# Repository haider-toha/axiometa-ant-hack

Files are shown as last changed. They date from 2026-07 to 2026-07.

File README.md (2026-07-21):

# Tacta

Tacta is an open project toward one wearable device. The device gives DeafBlind
people a sense of the world around them, through touch. It fuses several senses
into vibration.

Cameras read the scene. Microphones pick out important sounds. Depth sensors
feel the space around the wearer. Tacta turns all three into touch. The project
is open source so more people, more money, and better engineering can build the
real thing.

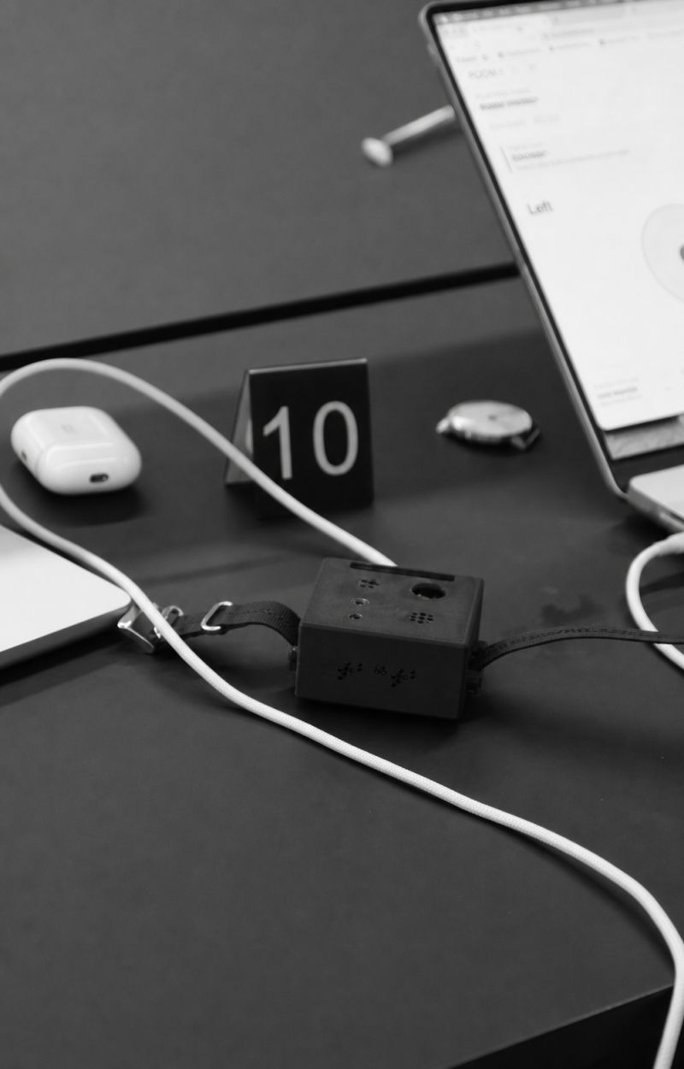
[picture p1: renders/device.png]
The Tacta prototype device


This repository holds a hackathon prototype. The team built it at the Axiometa
and Anthropic hardware hack in London, from 17 to 19 July 2026. The prototype
wires the idea end to end with off-the-shelf modules and a phone camera. It
locks the demo to one concrete scene so the story stays clear. The scene reads a
specific bus at a stop. That scene is one example, not the product.

> Honest scope. This is a hackathon prototype, not a finished accessibility
> product. The two on-board buzzers failed the bench haptic test. They now stand
> in as two audible tones for two future vibration channels. The single depth
> sensor gives a clearance warning, not navigation. The team has not tested Tacta
> with DeafBlind people. Read the [Limitations](#limitations) section.

## How it senses the world

Tacta fuses three channels. Each channel does a small job today. Each channel
points at a larger job in the real product.

### Vision

The cameras read the scene. Today, the phone camera sends frames to a cloud
vision service. The service finds objects and reads text, like a route number on
a vehicle or the words on a sign. A future version uses on-board cameras. It
reads more of the scene, including what is ahead and what is approaching.

### Sound

The microphones pick out important sounds. Today, one on-board microphone detects
a siren on the device, offline. A future version classifies more sounds. It can
flag a car horn, a barking dog, an alarm, or someone calling out.

### Depth

The depth sensors feel the space around the wearer. Today, one forward sensor
gives a clearance warning, not navigation. A future version senses a fuller field
around the body. It moves closer to a dome than a single line.

## System diagram

```mermaid
flowchart LR
  cam["Phone camera, capture page"] -->|"JPEG frames, 2 Hz"| modal["Modal vision service, YOLO and Claude"]
  modal -->|"reading and bearings"| relay["Vercel and Upstash relay"]
  relay -->|"outbound poll"| board["ESP32-S3 board"]
  mic["PDM microphone"] -->|"siren, local"| board
  depth["Depth sensor"] -->|"clearance, local"| board
  board --> out["Vibration output, two audible stand-ins today"]
```

## Hardware

An ESP32-S3 "Genesis Mini" board carries four snap-in modules. A phone browser
camera supplies the video. All four ports are occupied today.

| Port | Module | Function |
|---|---|---|
| `P1` | AX22-0018 passive buzzer | An audible tone at 2350 Hz. A stand-in for a future vibration channel |
| `P2` | VL53L0CX time-of-flight sensor | A forward clearance warning. Not navigation |
| `P3` | AX22-0018 passive buzzer | An audible tone at 3050 Hz. A stand-in for a future vibration channel |
| `P4` | AX22-0044 PDM microphone | Local siren detection |
| Phone camera | Phone browser camera | Live scene video through the capture page |

The end product puts the cameras, microphones, and depth sensors on one custom
board.

## Software stack

Four parts meet at the shared contract in
[`app/src/lib/contract.ts`](app/src/lib/contract.ts).

- **`app/`** is a Next.js 16 web app on Vercel and Upstash Redis. It serves the
  pitch deck at `/`. It runs the phone camera capture, the device relay, and the
  output and relay monitors. See [`app/README.md`](app/README.md).
- **`vision/service.py`** is a Modal service. It runs YOLO detection. Then Claude
  reads the route text under a strict JSON schema. The demo locks the reading to
  route 88 and Clapham Common. See [`MODAL-FOR-APP.md`](MODAL-FOR-APP.md).
- **The relay** runs on Vercel and Upstash Redis. It carries commands to the
  board. The board polls the relay outbound only. The board never accepts an
  inbound connection. See [`RELAY-FOR-FIRMWARE.md`](RELAY-FOR-FIRMWARE.md).
- **`firmware/braille_wearable/`** holds the PlatformIO firmware, environment
  `board_firmware`. It runs the local siren and depth paths offline. The
  directory keeps its old name so the firmware build does not break.

### Demo phases

The demo runs in two activity phases. The phone reports the phase.

- In `MOVING`, the board keeps the local depth and siren alerts active. It holds
  the arrival output silent. The cane stays the primary mobility aid.
- In `STILL`, the board stops the depth output. It keeps the siren active. It
  shows the arrival reading and the route-88 output.

Camera bearings (`LEFT`, `RIGHT`, `AHEAD`) are advisory. They tell the wearer
where the target sits in frame. They work in both phases. They never outrank the
local depth and siren paths.

## Quick start

Each area has its own doc with the full sequence. Do not copy flags from memory.

Start the web app from `app/`.

```bash
cd app
pnpm install
pnpm run build
```

See [`app/README.md`](app/README.md) for the dev server and the env setup.

Build the firmware from `firmware/braille_wearable/`.

```bash
cd firmware/braille_wearable
pio run -e board_firmware
```

For the rest, read the area docs. [`MODAL-FOR-APP.md`](MODAL-FOR-APP.md) deploys
the Modal vision service. [`RELAY-FOR-FIRMWARE.md`](RELAY-FOR-FIRMWARE.md) covers
the relay and the firmware contract. [`DEMO-RUNBOOK.md`](DEMO-RUNBOOK.md) runs the
demo with the stage sequence and the fallbacks.

## Repository map

| Path | Contents |
|---|---|
| [`app/`](app/) | Next.js 16 web app. Pitch deck, capture page, device relay, monitors |
| [`vision/`](vision/) | Modal vision service (`service.py`). YOLO detection and Claude route reading |
| [`firmware/`](firmware/) | PlatformIO ESP32-S3 firmware, environment `board_firmware` |
| [`cad/`](cad/) | Parametric enclosure (`enclosure.py`) with exported `enclosure.step` and `enclosure.stl` |
| [`demo/`](demo/) | Demo fixtures, including the synthetic siren audio |
| [`renders/`](renders/) | Device renders |
| [`docs/`](docs/) | Forward-direction notes, including the vibration-motor upgrade path |
| [`plan/`](plan/) | The authoritative plan |

## Limitations

This is a hackathon prototype. These limits are load-bearing, not disclaimers.

- Tactile output failed. The two AX22-0018 buzzers are audible stand-ins at
  2350 Hz and 3050 Hz. They are not working haptics. They prove nothing about
  body-worn vibration.
- The depth sensor is not navigation. The single forward zone gives a clearance
  warning only. No local sensor output is navigation.
- The team has not tested with DeafBlind people. This is a prototype, not an
  accessibility product. Nothing about us without us.
- Route 88 and Clapham Common are hardcoded on purpose. This is a demo lock, not
  general scene reading.

## Where this could go

The real product is purpose-built. This is the invitation to build it.

- One integrated device. A custom PCB carries the cameras, the microphones, and
  the depth sensors on one board.
- Real haptics. A proper array of vibration actuators replaces the two buzzers.
  See [`docs/lra-motor-upgrade.md`](docs/lra-motor-upgrade.md) for the near-term
  motor swap.
- A form factor that fits the wearer. It need not be a wrist unit. It can be a
  chest harness, a necklace, or something else.
- Richer sound. The microphones classify many sounds, not one siren.
- A fuller depth field. The sensors feel a field around the body, closer to a
  dome than a single line.

If you can build this properly, take it and run.

## Contributing

[`AGENTS.md`](AGENTS.md) documents the AI-assisted workflow. Claude Code and Codex
both work from that file. Read it before you change code. CI runs on every pull
request through [`.github/workflows/verify.yml`](.github/workflows/verify.yml).
Run the verification commands for the area you touch.

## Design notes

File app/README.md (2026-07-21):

# Tacta web app

This is the Next.js 16 web app for the Tacta prototype. It does four jobs.

1. It serves the pitch deck as the public landing page.
2. It captures phone camera frames and posts them to the Modal vision service.
3. It runs the outbound-only device relay that the ESP32 polls, backed by Upstash Redis.
4. It runs two debug monitors, one for the device output and one for the relay state.

The shared wire contract lives in [`src/lib/contract.ts`](src/lib/contract.ts).
It is the source of truth for the command, activity, and telemetry types. See
[`../MODAL-FOR-APP.md`](../MODAL-FOR-APP.md) for the Modal contract.

The stack is Next.js 16.2 (App Router), React 19, Tailwind v4 with shadcn on
Base UI, Upstash Redis, the Anthropic SDK, and Vitest.

## Pages

The landing route `/` serves the pitch deck. A rewrite in
[`next.config.ts`](next.config.ts) maps `/` to `public/deck/index.html`, so the
URL stays `/`. The deck is a static scrollytelling site. Its final call to
action links to `/capture`.

| Route | File | Function |
|---|---|---|
| `/` | `public/deck/index.html` (rewrite) | The pitch deck. A static scrollytelling site served at the site root |
| `/capture` | `src/app/capture/page.tsx` | The capture page. It opens the rear camera with `getUserMedia`. It grabs a `<canvas>` JPEG at 2 Hz (`CAPTURE_MS = 500`). It POSTs the base64 frame to the Modal detector (`NEXT_PUBLIC_MODAL_URL`, or `?modal=<url>`). It maps the detector response to a relay command and posts it on change. It also owns the `STILL` and `MOVING` activity control and the person-direction path |
| `/output` | `src/app/output/page.tsx` | The output monitor. It reads `TACTA_OUTPUT` telemetry from the ESP32 over Web Serial. It shows the P1 and P3 output channels and the pulse history. Desktop Chrome only |

## API routes

The API routes live under [`src/app/api/`](src/app/api/). All relay state lives
in Upstash Redis. The app writes the payload with `mset` before it increments
`seq`. This ordering is the race fix. Preserve it.

| Route | Method | Purpose |
|---|---|---|
| `/api/pull` | GET, POST | The ESP32's outbound poll. A POST body carries device telemetry, stored for the monitor. The response is the current `DeviceCommand`. A GET returns the command and writes no telemetry, which is handy for a `curl` smoke test |
| `/api/event` | POST | It ingests a camera-derived command and writes relay state. The command set lives in [`src/lib/contract.ts`](src/lib/contract.ts). It covers the arrival, wait, route-number, and unknown patterns, plus the advisory `LEFT`, `RIGHT`, and `AHEAD` bearings |
| `/api/activity` | POST | The `STILL` and `MOVING` activity channel and its heartbeat. It advances `activitySeq` and `activityTs` independently of the command `seq` and `ts` |
| `/api/person-direction` | POST | Person and obstacle handling in `MOVING`. It takes a normalized box and asks Claude which side has clear pavement. It fails closed. It uses `ANTHROPIC_API_KEY` at request time |
| `/api/detector` | POST | It records the raw Modal detector state for the debug screen |
| `/api/state` | GET | An aggregate debug snapshot of command, detector, and telemetry |

## Local development

```bash
pnpm install
cp .env.example .env.local
pnpm dev
```

The dev server runs at http://localhost:3000. Set the values from
[`.env.example`](.env.example).

| Variable | Needed for |
|---|---|
| `UPSTASH_REDIS_REST_URL`, `UPSTASH_REDIS_REST_TOKEN` | Relay state. `Redis.fromEnv()` requires both |
| `NEXT_PUBLIC_MODAL_URL` | The Modal detector endpoint the capture page POSTs to. Public, or pass `?modal=<url>` on `/capture` |
| `ANTHROPIC_API_KEY` | The request-time Claude call in `/api/person-direction` |

The production relay is https://tacta.space. Never commit `.env.local`. The repo
tracks only the empty `.env.example` template.

## Verification

```bash
pnpm exec tsc --noEmit
pnpm run lint
pnpm run build
pnpm test
```

`pnpm run build` can print Upstash missing-env warnings in a local shell. It must
still finish. Run the pre-demo readiness gate before the demo.

```bash
pnpm demo:readiness -- --base-url https://tacta.space
```

See [`../DEMO-RUNBOOK.md`](../DEMO-RUNBOOK.md) for the full readiness gate and the
fallbacks.

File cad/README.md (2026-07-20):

# Tacta wearable enclosure CAD

Tacta is a wearable that gives situational awareness through touch. This is the
parametric enclosure for the wrist-worn device. It wraps the Axiometa "Genesis
Mini" host board (55 x 55 mm) and its four snap-in AX22 modules.

| Port | Module | Aperture in the shell |
|---|---|---|
| P1 / P3 | passive buzzers | two buzzer grilles |
| P2 | VL53L0CX ToF | one ToF "eye" |
| P4 | microphone | mic port(s), this module governs the deck height |

The shell is a **closed monolith**. A solid deck carries only functional
openings. These are the ToF eye, the mic ports, the trimpot access, the buzzer
grilles, and a button-access slot. The one decorative feature is the raised
"TACTA" branding on the −X wall. It pierces nothing and is **not** an
accessibility feature.

## `enclosure.py`

`enclosure.py` is a **Fusion 360 Python script**. It authors every
dimension in millimetres. It converts to Fusion's internal centimetres through a
single `_cm()` chokepoint. It produces two bodies. `cage` holds the shell, lugs,
strap bars, and branding. `skin_plate` holds the base plate, corner gussets, and
M2 standoffs. So the base carries the board, and the cage drops over it.

**In Fusion.** Open a Design document. Then open *Utilities*, *Add-Ins*,
*Scripts and Add-Ins*. Add this file and run it. The Fusion entry point is
`run(context)`.

**Headless, no Fusion.** The script falls back to
[`tests/fake_adsk/`](tests/fake_adsk). This is a real
[build123d](https://github.com/gumyr/build123d) geometry engine behind a fake
`adsk` API. So it builds and **exports STEP and STL** without the Fusion GUI.

```bash
python cad/enclosure.py
```

This writes `enclosure.step` and `enclosure.stl` as fit-check
artifacts. The headless harness records chamfers but does not apply them. So the
exported solids are sharp-edged relative to the in-Fusion build.

## `reference/`

[`reference/genesis-mini-shell.step`](reference/genesis-mini-shell.step) is a
**known-good, physically printed** Genesis Mini shell from Printables. It serves
as the fit reference. This shell already seats the board and modules. Check
openings, clearances, and envelope against it before you trust our own model
alone. See [`reference/README.md`](reference/README.md) for provenance and its
different original module layout.

## `tests/`

Fusion has no headless mode. So geometry-logic bugs otherwise surface only inside
the GUI. These bugs include boolean-miss cuts, sketch-plane orientation
assumptions, and dimension regressions. The suite runs the enclosure script
**offline** against `fake_adsk` and probes the result. It catches that whole
class of bug without Fusion.

```bash
.venv/bin/python -m pytest cad/tests -q
```

The venv needs `pytest` and `build123d`. If it is absent, the geometry suite
cannot run. The in-Fusion build remains ground truth. This suite is a fast
regression net, not a substitute. See [`tests/README.md`](tests/README.md) for
what the harness can and cannot catch.

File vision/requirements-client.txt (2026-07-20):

# Dependencies for `python vision/client.py`, the local test client.
#
# Separate from requirements.txt on purpose: that file is scoped to the machine
# that runs `modal deploy` and lists only what service.py imports at module
# level. A camera/GUI dependency does not belong there.
#
#   pip install -r vision/requirements-client.txt
#
# The browser capture path (app/src/app/capture/page.tsx) needs nothing installed here.

# The only non-stdlib import in client.py. HTTP goes through urllib.request,
# so there is no `requests` dependency to pin.
opencv-python

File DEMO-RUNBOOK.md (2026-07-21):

# Tacta Demo Runbook

Tacta is an open project toward one wearable that gives DeafBlind people
situational awareness through touch. It fuses cameras, microphones, and depth
sensors and delivers the result as vibration. This runbook drives the hackathon
demo. The demo hardcodes one concrete scene, reading a specific bus at a stop,
route `88` / `Clapham Common`. That scene is one hardcoded example of the
product, not the product itself.

The cane remains the primary mobility aid. The single forward ToF sensor detects
clearance only. It cannot choose a safe left or right bypass. The buzzers are
audible stand-ins for two future vibration channels. The first-hour tactile test
failed, so treat them as proxies only. Nothing here is validated with DeafBlind
users.

The live site tacta.space serves the pitch deck as the landing page. The demo
tools live at `/capture` and `/output`.

## Readiness Gate

Run the readiness command from `app/`.

```bash
pnpm demo:readiness -- --base-url https://tacta.space
```

Do not start the audience demo until it prints `READY`. Haider owns the phone
motion classifier and the relay activity heartbeat. This repo consumes that
state. It does not replace the producer.

The morning demo firmware boots in `AUDIBLE` mode. This stops a reset or power
cycle from disabling P1 and P3 without warning. Send service Serial `q` for a
deliberate quiet rehearsal. Sensors, relay handling, and `TACTA_OUTPUT`
telemetry continue while the buzzer GPIO drives stay muted.

## Hardware And Topology

| Port | Module | Firmware signal |
|---|---|---|
| P1 | AX22-0018 passive buzzer | GPIO3, left/channel A |
| P2 | VL53L0CX ToF | SDA GPIO10, SCL GPIO11, XSHUT GPIO6 |
| P3 | AX22-0018 passive buzzer | GPIO16, right/channel B |
| P4 | AX22-0044 PDM microphone | CLK GPIO18, data GPIO17, select GPIO1 high, I2S0 |

The phone runs Chrome or Safari at the deployed `/capture` route on a 2.4 GHz
hotspot. The ESP32 joins the phone hotspot and polls Vercel outbound only. The
MacBook powers the ESP32 over USB-C. The MacBook opens the deployed `/output`
route in desktop Chrome for Web Serial.

PlatformIO Serial Monitor and `/output` cannot own the USB serial port at the
same time. Close one before you open the other.

## Morning Setup

1. Pull `main` and confirm it includes the audible-default demo firmware.
2. Create the ignored file `firmware/braille_wearable/src/secrets.h` from
   `secrets.example.h`. Add only the phone hotspot SSID and password. The file
   `network_config.h` tracks the deployed relay host.
3. Enable the phone hotspot. On iPhone, enable **Maximize Compatibility**. On
   Android, choose the 2.4 GHz band.
4. Build and upload `board_firmware`.

   ```bash
   cd firmware/braille_wearable
   $HOME/.platformio/penv/bin/pio run -e board_firmware
   $HOME/.platformio/penv/bin/pio run -e board_firmware -t upload --upload-port /dev/cu.usbmodem1101
   ```

5. Confirm the board boots in `AUDIBLE` mode. Send `q` only for a quiet
   rehearsal. Send `v` before the audience demo.
6. Open `/capture` on the phone, grant camera access, and frame the A4 route prop.
7. Open `/output` in desktop Chrome. Select the ESP32. Confirm live idle
   telemetry. The display shows the requested logical frequencies in either
   output mode.
8. Run the readiness command until every route, contract, and activity
   freshness check passes.
9. Wait for the board to record its first activity baseline. Then make Haider's
   producer send a fresh `MOVING` transition. A baseline alone does not grant
   cloud control.

## Exact Demo Sequence

1. **Moving.** Confirm `/api/pull` reports fresh `MOVING`. Bring a blockade into
   the forward ToF zone. Expect P1 proximity pulses on `/output`. Choose the
   bypass with the cane and verify it. Then clear the blockade.
2. **Ambulance.** In daytime only, play the validated siren sample at the
   rehearsed level. Expect the local siren output to preempt proximity and
   signal a stop. Do not claim general environmental-sound recognition.
3. **Still.** Haider's producer changes activity to fresh `STILL`. Confirm the
   readiness probe still passes. Confirm the board suppresses ToF output.
4. **Direction (audit 23).** While `STILL`, hold the route prop to one side of
   the camera frame. Wait for the three-frame confirmation. Then expect `LEFT`,
   `RIGHT`, or `AHEAD` on `/output`. Bearings deliver in **both** activity
   phases. The user scans for the target while standing still. While an arrival
   or route reading is active, that information takes the shared channel first.
   The capture page then shows the direction as `held (…)`. The "Force send"
   toggle on `/capture` makes the direction outrank it.
5. **Arrival.** Move the printed route-88 prop steadily through the phone camera.
   Expect `BUS`, then `WAIT`, then a high-confidence `NUMBER` with route `88`.
6. **Output.** Confirm `/output` shows both logical channels and the pulse
   history. In audible mode, the buzzers mirror those signals. In night mode,
   the buzzers stay muted.
7. **Reset.** Remove the prop. Return activity to fresh `MOVING` before the next
   run.

## Output Controls

Use service Serial only while `/output` is disconnected.

| Key | Result |
|---|---|
| `q` | Night mode. Hardware muted, logical patterns and telemetry continue |
| `v` | Audible mode. Energize the buzzers for a daytime rehearsal |
| `x` | Emergency stop. Clear all output, sensing continues |
| `o` | Resume output processing after `x` |
| `n` / `s` | Diagnostic MOVING/STILL override |
| `c` | Clear diagnostic override and return control to Haider's relay state |
| `b` / `w` / `8` | Diagnostic BUS/WAIT/NUMBER-88 inputs |

The Serial connection can reset the board when you open it. The morning demo
build returns to audible output after that reset. Send a control, then close
Serial Monitor before you reconnect `/output`.

## Fallbacks And Stop

- For stale or missing activity, use `n` or `s` only as a disclosed diagnostic
  fallback. Do not present it as phone motion classification.
- For a vision or Modal failure, use `b`, `w`, and `8` only as a disclosed
  board-only fallback. Do not claim the board read the printed route.
- For a deployed `/output` failure, run `pnpm dev -- -p 3012` from `app/`. Then
  open `http://localhost:3012/output` in Chrome.
- For an unreadable or low-confidence route, expect `UNKNOWN`. Never substitute
  `88`.
- For an unexpected sound, send `q`. If output continues, send `x`. Then
  disconnect USB-C power.
- For a full stop, stop camera capture, return relay activity to `MOVING`, send
  `q`, disconnect `/output`, and unplug the board.

## Five-Minute Rehearsal

- The readiness command prints `READY`.
- The board holds hotspot credentials and starts in audible mode.
- `/capture` sees the complete A4 prop in stable light.
- `/output` receives fresh telemetry in desktop Chrome.
- Fresh `MOVING` produces the ToF visualization. Fresh `STILL` suppresses it.
- `BUS`, `WAIT`, and `NUMBER` 88 arrive in order while `STILL`.
- `q` and `x` stop hardware output as expected before you admit an audience.

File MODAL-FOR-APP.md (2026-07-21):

# Web app to Modal vision contract

This is the handoff spec for the Modal vision service (`vision/service.py`). It defines the one HTTP contract that the web app (`app/`) speaks to Modal. Get this shape right, and the front end needs no changes.

Tacta gives situational awareness through touch. It fuses cameras, microphones, and depth sensors and delivers the result as vibration. This endpoint is the vision sense. The demo hardcodes one concrete scene, reading a specific bus at a stop, route `88` to `Clapham Common`. That scene is one hardcoded example, not the product. The web app that calls this endpoint ships on the live site tacta.space, which serves the pitch deck as its landing page and the demo tools at `/capture` and `/output`.

The source of truth for the types is [`app/src/lib/contract.ts`](app/src/lib/contract.ts). It exports `ModalResponse`, `ModalReading`, and `detectorToEvent`. For full background, read [`plan/2026-07-18-situational-awareness.md`](plan/2026-07-18-situational-awareness.md). See the sections "Data Contracts, Contract A" and "The Vision Pipeline".

---

## Summary

- Expose **one public HTTPS POST endpoint** on Modal as a web endpoint. Callers need **no auth**. The browser posts directly to it.
- The web app sends a JPEG frame about **2 times per second**. The endpoint replies with the current **arrival state**, not a bounding box.
- The endpoint must send **CORS headers and answer the `OPTIONS` preflight**. The call is cross-origin from the browser. This is the single most common thing that breaks it.
- The web app needs only the **deployed URL** back from you. It goes into the app as `NEXT_PUBLIC_MODAL_URL`, or as `?modal=<url>` on the capture page. The Modal **token** is for deployment, not for the app. Never put it in `app`.

---

## The endpoint

`POST https://<workspace>--tacta-vision-ingest.modal.run` (name is up to you)

### Request body (what the phone sends)

```jsonc
{
  "frame_b64": "/9j/4AAQSkZJRg…",  // base64 JPEG, NO "data:image/jpeg;base64," prefix
  "force": false                    // true only for the disclosed SPACE-key demo aid
}
```

- `frame_b64` is a raw base64 JPEG, about 1280x720, q85, about 120 kB. The browser already strips the data-URL prefix. Decode it directly.
- When `force` is `true`, run the arrival and read path even if the debounce would not normally fire. Use `force` once, on stage, to trigger a detection on demand. Treat `false` as the default.

### Response body (exact shape the app expects)

```jsonc
{
  "event": "NONE",          // "NONE" | "BUS_ARRIVED" | "BUS_GONE"
  "present": true,          // is the target vehicle in frame this instant
  "confidence": 0.83,       // best detection-box confidence this frame (0..1)
  "arrival_id": 1,          // increments by 1 ONCE per arrival, the fire-once latch
  "reading": null,          // null until the route has been read; then the object below
  "reading_ready": false,   // true once `reading` is populated
  "votes": []               // raw route strings from the read step, e.g. ["88","88","88"]
}
```

After the route is read, `reading` holds this object.

```jsonc
{ "route": "88", "destination": "Clapham Common", "confidence": "high" }  // confidence: "high" | "low"
```

The app parses this into the following TypeScript.

```ts
interface ModalReading { route: string; destination: string; confidence: "high" | "low"; }
interface ModalResponse {
  event: "NONE" | "BUS_ARRIVED" | "BUS_GONE";
  present: boolean;
  confidence: number;
  arrival_id: number;
  reading: ModalReading | null;
  reading_ready: boolean;
  votes: string[];
}
```

Keep the JSON keys **exactly** as above. Use snake_case, for example `frame_b64`, `arrival_id`, and `reading_ready`.

---

## CORS is required

The browser posts cross-origin with `Content-Type: application/json`. This triggers a **preflight**. The endpoint must do two things.

- Answer `OPTIONS` with `204` and the CORS headers below.
- Include `Access-Control-Allow-Origin: *` on the `POST` response, or the deployed web-app origin.

```
Access-Control-Allow-Origin: *
Access-Control-Allow-Methods: POST, OPTIONS
Access-Control-Allow-Headers: Content-Type
```

Without these headers, the frames never leave the browser. You see nothing server-side.

---

## Why Modal is a server, not just Claude

The endpoint delivers a **state transition**, not a per-frame detection. It must hold about 1 to 2 seconds of history. It does three things that the stateless model cannot do.

1. **Detect** the target vehicle in each frame with YOLO or equivalent. Set `present` and `confidence`.
2. **Debounce and latch.** Require about 2 consecutive detections before you fire. One flickery frame then does not fire, and one dropped frame does not un-fire. On the rising edge, set `event: "BUS_ARRIVED"` and **increment `arrival_id` once**. Emit `BUS_GONE` when the target leaves.
3. **Read once per arrival.** After the latch, crop the destination blind and ask Claude to read the route and destination with structured output. Run a few concurrent reads and vote. When they agree, set `reading`, `reading_ready: true`, and `votes`. Do this **once per `arrival_id`**, not every frame.

State must persist across frames. The shipped `vision/service.py` keeps the arrival state machine **and** the Claude reading in Upstash Redis. An atomic Lua script mutates that state. It stays correct even when consecutive polls land on different containers, so it needs no `max_containers` cap. If you skip Redis, a simpler alternative pins **`max_containers=1`** and holds the arrival state in process.

Latency matters. Keep the container **warm**. The arrival signal (stage 1) must land fast. The whole two-stage haptic (coarse then precise) depends on a quick arrival pulse. The route follows a couple of seconds later.

---

## How the web app uses each field (so the shape makes sense)

The capture page maps your response to a device command with `detectorToEvent()`.

| Your response | Device command the app fires |
| --- | --- |
| `event: "BUS_ARRIVED"`, no reading yet | `BUS`, meaning "arrival detected" |
| `arrival_id > 0`, `present`, reading pending | `WAIT`, meaning "reading it" |
| `reading_ready`, `reading.confidence: "high"`, digit route | `NUMBER` (route), buzzes "88" |
| `reading_ready`, low confidence or non-digit route | `UNKNOWN` |
| otherwise | `NONE` |

`arrival_id` must increment exactly once per real arrival. `reading_ready` must flip to `true` only when `reading` is actually populated. Those two fields drive the whole flow.

The app posts a fresh command to its own relay **only when the meaning changes**. A stable response across frames is therefore fine and expected.

---

## Auth and deployment

- **Callers need no credentials.** It is a public web endpoint.
- The `modal token set --token-id … --token-secret …` credential is for deployment. You run `modal deploy` or `modal serve` with it, and it lives in `~/.modal.toml` on your machine. **Never** commit it or put it in any `NEXT_PUBLIC_*` var.
- Hand back the **deployed URL**. That is all `app` needs. The URL differs between `modal serve`, which adds a `-dev` suffix, and `modal deploy`. Send whichever one you run.

---

## Minimal Modal sketch (illustrative)

```python
import modal

app = modal.App("tacta-vision")
image = modal.Image.debian_slim().pip_install("ultralytics", "anthropic==0.117.0")

@app.cls(gpu="T4", image=image,
         secrets=[modal.Secret.from_name("anthropic"), modal.Secret.from_name("upstash")])
class Detector:
    # ~2 s of detection history + the arrival_id latch + Claude reading live in
    # Upstash Redis (see service.py), so concurrent containers stay consistent
    @modal.fastapi_endpoint(method="POST")
    def ingest(self, body: dict):
        # 1. decode base64 JPEG, run YOLO -> present/confidence
        # 2. debounce -> on rising edge: event=BUS_ARRIVED, arrival_id += 1
        # 3. once per arrival_id: crop + Claude read (structured output) -> reading/votes
        # 4. return the ModalResponse shape above, WITH CORS headers
        ...
```

Add the CORS headers and an `OPTIONS` handler on the FastAPI response. The sketch omits them for brevity, but they are required.

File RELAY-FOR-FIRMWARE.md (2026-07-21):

# Relay to firmware command contract

This is the handoff spec for the wristband firmware on the live `app` relay.
Commands and the independent `STILL` and `MOVING` activity channel are deployed.
Haider owns the phone motion classifier and the activity producer. Service
Serial remains available for deterministic board testing.

Tacta gives situational awareness through touch, delivered as vibration. The
demo hardcodes one concrete scene, reading a specific bus at a stop, route `88`
to `Clapham Common`. That scene is one hardcoded example. The command vocabulary
below is the real product surface.

The source of truth for the types is
[`app/src/lib/contract.ts`](app/src/lib/contract.ts). It exports `DeviceCommand`,
`Telemetry`, and `CloudPattern`. For background, read
[`plan/2026-07-18-situational-awareness.md`](plan/2026-07-18-situational-awareness.md).
See "Data Contracts, Contract C".

---

## Summary

- The host is `tacta.space`, tracked in `network_config.h`. That site serves the
  pitch deck as its landing page and the demo tools at `/capture` and `/output`. The file `secrets.h` contains only hotspot credentials.
- The board **POSTs to `/api/pull` about every 300 ms**. The request body is
  telemetry. The response is the current command.
- The response is `{ seq, pattern, route, dest, conf, arrivalId, ts, activity, activitySeq, activityTs }`,
  **not** the old `{ seq, mode, msg, replies }`.
- Activity version and freshness are independent from command `seq` and `ts`. An
  activity heartbeat must never re-fire a command.
- **`/api/reply` is gone.** Remove it. Telemetry now rides on the `/api/pull`
  POST body.
- **`seq` is still the edge-trigger.** Act only when `seq` advances past the last
  one you handled.
- The relay accepts camera bearings (`LEFT`, `RIGHT`, `AHEAD`) in both known
  activity phases. `MOVING` suppresses `BUS`, `WAIT`, `NUMBER`, and `UNKNOWN`.
  `STILL` accepts them. `ERROR` is global.
- Only wire route `"88"` with `conf="high"` may drive the hardcoded route-88
  pattern. The board consumes and logs a different route or lower confidence
  without a false `88` signal.
- The first command and activity snapshots after boot or a long outage are
  baselines. They never fire output.

The old speech app at `app-eight-lyart-98.vercel.app` is **retired**. Do not poll
it.

---

## The poll

`POST https://tacta.space/api/pull` about every 300 ms.

- The **request body** is telemetry (see below). The relay stores it for the
  debug screen, then returns the command.
- The **response** is the current `DeviceCommand`.
- `GET /api/pull` also works. It returns the command and writes no telemetry,
  which is handy for a `curl` smoke test.

```bash
curl -fsS https://tacta.space/api/pull
# {"seq":20,"pattern":"UNKNOWN","route":"","dest":"","conf":"low","arrivalId":1,"ts":1784398000652}
```

### Response, the command to parse

```jsonc
{
  "seq": 20,            // monotonic. Only act when it advances. THE trigger.
  "pattern": "NUMBER",  // CloudPattern (see below)
  "route": "88",        // always a JSON string, 1 to 3 digits; "" unless pattern==NUMBER
  "dest": "Clapham Common", // debug-screen only, parse and DISCARD on device
  "conf": "high",       // "high" | "low" | ""
  "arrivalId": 1,       // increments once per arrival
  "ts": 1784398000652,  // ms epoch of the server write, command timestamp
  "activity": "STILL", // "MOVING" | "STILL"
  "activitySeq": 4,     // increments on transitions and 30 s heartbeats
  "activityTs": 1784397999000 // activity write time; independent of command ts
}
```

All three activity fields are required together. The first complete, valid
snapshot establishes a non-rendering baseline. Missing, invalid, regressed, or
older-than-120-second activity data falls back to `MOVING`. Every phone POST,
including the 30-second heartbeat, advances `activitySeq` and refreshes
`activityTs` without changing command `seq` or `ts`.

### JSON field to firmware struct

| JSON field | Type on wire | Firmware | Notes |
| --- | --- | --- | --- |
| `seq` | number | `long` | Edge-trigger. `if (seq <= s_lastSeq) return;` then `s_lastSeq = seq`. |
| `pattern` | string | `uint8_t` enum | Map the string to `PAT_*` **once**, at parse time. Never keep the `String`. |
| `route` | string | `char[8]` | Always a JSON string, even `"88"`. Digits only (server rejects letters). Copy into a fixed buffer, no heap. |
| `dest` | string | none | **Parse and discard.** No display on the device. |
| `conf` | string | `uint8_t` enum | `""` becomes `CONF_NONE`, `"low"` becomes `CONF_LOW`, `"high"` becomes `CONF_HIGH`. |
| `arrivalId` | number | `long` | Use it to de-duplicate repeated arrivals if needed. |
| `ts` | number | `long`/`int64` | Optional staleness guard. Ignore commands older than N seconds. |
| `activity` | string | `uint8_t` enum | Exact `MOVING` or `STILL`. Missing or invalid falls back to `MOVING`. |
| `activitySeq` | number | `uint32_t` | Independent edge. Must not increment command `seq`. |
| `activityTs` | number | `int64_t` | Activity write time. Must not refresh command `ts`. |

The firmware uses this fixed-size command struct, with no `String` and no heap.

```c
enum : uint8_t { CONF_NONE = 0, CONF_LOW, CONF_HIGH, CONF_INVALID };

struct DeviceCommand {
    uint32_t seq      = 0;
    uint8_t pattern   = PAT_INVALID; // string to enum ONCE, at parse time
    char    route[8]  = {0};        // "88" or "205"
    uint8_t confidence = CONF_INVALID;
    uint32_t arrivalId = 0;
    int64_t serverTs  = 0;
};
```

### `pattern` values, the cloud vocabulary

The relay sends these nine values. Map each one to the corresponding firmware enum.

| `pattern` | Meaning | Device pattern |
| --- | --- | --- |
| `NONE` | no active command | idle |
| `LEFT` | camera target is left of frame | P1 proxy pattern |
| `RIGHT` | camera target is right of frame | P3 proxy pattern |
| `AHEAD` | camera target is centred | both-channel proxy pattern |
| `BUS` | arrival detected | P5 BUS ARRIVING |
| `NUMBER` | route is in `route` | P6 ROUTE NUMBER |
| `WAIT` | reading the route now | P7 WAIT |
| `UNKNOWN` | could not read or low confidence | P8 UNKNOWN |
| `ERROR` | degraded | P10 ERROR |

The board generates the **device-local** patterns READY, DANGER, SIREN,
ATTENTION, PROXIMITY, and ACK. They **never come over the wire**. Camera bearings
are advisory target-location cues. The single forward ToF zone never derives a
bypass direction.

### Activity gate and local sensing

| Effective activity | Relay output | ToF | Siren |
|---|---|---|---|
| `MOVING` | Consume but suppress arrival-information patterns. Accept `ERROR`. | Sample and allow local proximity output. The cane remains primary. | Sample and allow local output. |
| `STILL` | Accept fresh arrival-information patterns and `ERROR`. | Continue to sample for health and telemetry. Clear and suppress proximity output. | Sample and allow local output. |
| missing or stale | Arrival-information gate closed. Fallback behavior is `MOVING`. | Sample and allow local proximity output. | Sample and allow local output. |

A command suppressed while moving advances `lastSeq` immediately. It can never
replay simply because activity later changes to still.

---

## Physical hotspot and relay smoke, 2026-07-18

We tested this on the Genesis Mini through an iPhone hotspot with **Maximize
Compatibility** enabled. The board joined the 2.4 GHz hotspot. It POSTed
telemetry to the deployed Vercel route. It established the existing sequence 20
`UNKNOWN` value as a non-rendering baseline. We then observed the following live
relay edges over Serial.

| Relay edge | Effective activity | Physical result |
|---|---|---|
| sequence 21, `NUMBER`, route `88`, `conf=high` | service `STILL` | accepted. The route-88 waveform appeared on both output telemetry channels |
| sequence 22, same route result | service `MOVING` | consumed and logged as suppressed. Both channels remained off |
| sequence 23, `NONE` | service `MOVING` | consumed with no output. The shared relay stayed neutral |

ToF also entered proximity during both phases. It produced local channel-A
pulses while `MOVING`. The board logged it as suppressed while `STILL`.
Microphone frames stayed `HEALTHY` throughout this smoke. This is a bench
integration check, not accessibility or outdoor validation.

### ESP32 HTTP gotcha, Vercel uses chunked responses

The deployed `/api/pull` response can omit `Content-Length` and use
`Transfer-Encoding: chunked`. Arduino-ESP32 3.3.9 `HTTPClient::getStream()`
exposes the raw chunk framing. So a direct pass of that stream to ArduinoJson
fails with `InvalidInput`, even though `curl` shows valid JSON. Firmware must
first call `HTTPClient::getString()`, which de-chunks the response. Then it
enforces the 768-byte response limit. Only then does it deserialize. A direct
`getStream()` regression reproduces as repeated
`RELAY rejected=json error=InvalidInput`, then capped poll backoff.

---

## Telemetry, the POST request body

Send this as the `/api/pull` request body on each poll. The debug screen then
shows what the device does. All fields are best-effort. The server coerces or
defaults anything missing.

```jsonc
{
  "bandRms": 312.4,      // siren band RMS
  "peakHz": 940,         // dominant siren-band bin
  "modIdx": 0.62,        // 2 to 4 Hz modulation index
  "trend": "rising",     // "rising" | "flat"
  "playing": "NUMBER",   // the pattern currently on the buzzers (PatternId string)
  "tofMm": 842,          // ToF distance
  "upMs": 93000,         // uptime ms
  "rssi": -58            // Wi-Fi RSSI
}
```

`playing` is the full device vocabulary (for example `READY`, `DANGER`,
`PROXIMITY`, `ACK`, and more), not just the cloud six. It reflects what actually
buzzes.

---

## Remove from the old firmware

- Remove the parse code for `mode`, `msg`, and `replies`. These are the old
  contract.
- Remove the `POST /api/reply` call and its endpoint. It is gone in `app`.
- Remove anything that reads the retired `app-eight-lyart-98.vercel.app`.

---

## TLS keep-alive makes 300 ms polls viable

The firmware now owns one static `WiFiClientSecure` and one static `HTTPClient`.
It calls `setReuse(true)` and never overlaps polls. The healthy cadence is
300 ms. Failures use a capped 1, 2, 4, and 8-second backoff. Wi-Fi and TLS run
only on Core 0 and never block local sensor startup.

The relay is a latest-value register, not a queue. If the producer overwrites
`BUS` with `WAIT` between polls, firmware cannot recover `BUS`. It can only
report a sequence gap. Hold a transient `BUS` for at least about one second for
the demo. Or add queue and ack semantics on the web side.

---

## Keep the two in lockstep

`contract.ts` is the command-side source of truth. Add the activity extension
there before you treat it as deployed. If a field or enum changes, update the
fixed firmware structs and host tests in the same change. The `route` buffer, the
exact route-88 guard, and the command and activity sequence independence are the
highest-risk drift points.

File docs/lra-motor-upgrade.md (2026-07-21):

# LRA Motor Upgrade Note

## Status

Tacta delivers situational awareness through touch. Purpose-built vibration
motors are how the wearable will reach that goal. This is the migration path from
the current AX22-0018 passive-buzzer proxies to two AX22-0039 LRA motor modules. It assumes the modules physically fit the same
P1 and P3 sockets. It does **not** assume that the current direct-GPIO firmware
can drive them. It does **not** assume that left and right tactile discrimination
is already validated.

Treat replacement as a powered-off module swap, not a live hot-plug.

## Part identity must be confirmed first

Axiometa calls the product **LRA Motor (DA7820)**. Axiometa says it combines an
LD0825BC LRA with a DA7820 haptic driver. However, the Arduino example on the
same product page includes `Haptic_Driver.h` and identifies it as the SparkFun
DA7280 driver. Renesas publishes a DA7280 haptic driver. We have not found a
matching DA7820 primary datasheet.

Before you write the production driver, check the IC marking or the Axiometa
schematic. Confirm whether the module actually uses DA7280. The requirements
below use the DA7280 interface as the likely implementation, not as a verified
module fact.

See these references.

- [Axiometa AX22-0039 product page](https://www.axiometa.io/products/lra-motor-da7820)
- [Renesas DA7280 product page](https://www.renesas.com/en/products/da7280)
- [Renesas DA7280 datasheet](https://www.renesas.com/en/document/dst/da7280-datasheet)

## Hardware migration

Keep the conceptual and visible mapping unchanged.

| Port | Meaning | Current module | Target module |
|---|---|---|---|
| P1 | LEFT | AX22-0018 buzzer | AX22-0039 LRA |
| P3 | RIGHT | AX22-0018 buzzer | AX22-0039 LRA |

The LRA module includes its own motor driver. Firmware must control that driver.
It must not drive the motor directly with the buzzer GPIO tone signal. Axiometa
lists a 240 Hz rated LRA, 3.3 V and 5 V support, up to 90 mA drive, and I2C plus
hardware trigger pins.

Confirm the following before you install two modules.

1. Confirm P1 and P3 expose the module's `SDA`, `SCL`, power, ground, interrupt,
   `GPIO0`, and `GPIO1` pins as expected.
2. Confirm the Genesis Mini rail can supply both modules concurrently, including
   startup and braking transients, while Wi-Fi and the remaining sensors run.
3. Confirm the enclosure couples each LRA firmly to the wearer. It must not block
   the motor's moving mass or let the PCB resonate loosely.
4. Confirm the P1 and P3 control topology. DA7280 has a fixed 7-bit I2C address
   of `0x4A`. You cannot control two devices at that address independently on one
   shared I2C line.

The preferred dual-module options, in priority order, are the following.

1. Use separate I2C controllers or buses if P1 and P3 route `SDA` and `SCL`
   separately.
2. Add an I2C multiplexer or switch if both sockets share one line.
3. Investigate preconfigured DA7280 waveform sequences. Trigger them through each
   socket's independent `GPIO0` and `GPIO1` lines. This still needs a way to
   configure each same-address device independently at startup. So it is not
   automatically a mux-free solution.

Do not implement a two-device driver until you verify one of these topologies on
the Genesis Mini schematic or bench.

## Firmware migration

The existing `hapticWrite(leftHz, rightHz)` implementation uses ESP32 LEDC tone
output. Preserve the pattern scheduler and channel semantics, but put the
actuator-specific work behind a driver boundary.

The recommended target behavior is the following.

- `hapticBegin()` initializes both drivers, applies the verified motor profile,
  enables resonance tracking, and clears stale interrupts. It fails safely with
  both channels off if it cannot initialize either required device.
- Replace frequency arguments with actuator-neutral channel levels, for example
  `hapticWrite(leftLevel, rightLevel)`, where `0` is off and `1..127` is drive
  strength. Keep the conversion to percentages at the UI boundary.
- Preserve non-blocking pattern timing. The Axiometa example uses `delay()`, but
  the integrated firmware must not block ToF, microphone, relay, or safety work.
- `hapticStop()` must stop both channels immediately, including after an I2C
  error, mode change, reset, or higher-priority alert.
- Read interrupt and fault state where available. Degrade to off rather than
  leave an actuator latched on.
- Keep local ToF and siren paths independent of Wi-Fi.
- Do not translate 2350 Hz and 3050 Hz into LRA frequencies. Those values are
  audible-buzzer proxies. Design a new tactile vocabulary from channel,
  amplitude, pulse duration, rhythm, and possibly stored waveforms.

Add native tests for the pattern to channel and level mapping. Add hardware tests
for left-only, right-only, both, off, stop latency, initialization failure, and
I2C failure. The ESP32 target build remains a required check.

## Serial protocol migration

Keep protocol v1 in use while the buzzer firmware runs.

```text
TACTA_OUTPUT {"v":1,"leftHz":2350,"rightHz":0,"upMs":123456}
```

Add an actuator-neutral v2 record when the LRA firmware lands.

```text
TACTA_OUTPUT {"v":2,"kind":"lra","leftLevel":127,"rightLevel":0,"upMs":123456}
```

Follow these v2 rules.

- `kind` is `"lra"` for this module family.
- `leftLevel` and `rightLevel` are integers from `0` through `127`. `0` means
  off.
- `upMs` keeps its v1 reset, order, and heartbeat meaning.
- Emit immediately on state change, and at most once per second while unchanged.
  This matches v1 behavior.
- Report the state actually written to the drivers. Do not report the requested
  relay command. Do not report an inferred semantic such as `BUS` or `SIREN`.
- If you later need diagnostics, add explicit optional fault fields in another
  reviewed protocol revision. Do not overload level values.

Deploy browser support for both v1 and v2 before you flash v2-only firmware. This
keeps the laptop useful during a mixed buzzer and LRA transition.

## Laptop UI migration

The `/output` route remains the correct crowd display. Its physical layout and
serial lifecycle do not need to change. This route is one of the demo tools on
the live site tacta.space, next to `/capture`. That site serves
the pitch deck as its landing page.

- Keep `LEFT / P1` and `RIGHT / P3` in fixed positions.
- Keep active motion, color-independent state, pulse history, stale detection,
  disconnect handling, and reconnect behavior.
- Parse telemetry as a versioned union. Do not assume every record contains
  hertz.
- For v1, continue to show frequency in hertz. Identify the output as a buzzer or
  audio proxy.
- For v2, show `LRA` and strength as a percentage derived from `level / 127`.
  `level > 0` drives the active animation.
- Preserve the rule that the UI shows physical output only. It must not invent
  navigation or hazard meaning from a motor pulse.

No desktop daemon or phone-to-laptop link is required. The phone continues to use
the web and relay path. The laptop reads physical-output telemetry over USB
serial.

## Physical acceptance gate

The upgrade is ready only after all of these pass on the assembled device.

- Both modules enumerate or initialize independently with no I2C-address
  collision.
- Left-only, right-only, both, and off commands actuate exactly the intended
  channels with no crosstalk.
- Emergency stop and fault paths turn both motors off promptly.
- ToF, microphone, Wi-Fi relay, and serial heartbeat remain responsive during
  sustained and alternating vibration.
- The laptop display starts and stops in sync with each physical channel. It
  recovers after USB disconnect and reconnect.
- Current draw, temperature, mechanical retention, noise, and comfort are
  acceptable for the demo duty cycle.
- A wear test establishes whether the chosen left and right patterns are actually
  distinguishable. Physical separation remains 33.941 mm. So make no spatial
  localization claim without evidence.

## Recommended implementation order

1. Confirm the actual driver IC and the P1 and P3 I2C and pin topology.
2. Bring up one LRA module and verify start, level control, stop, and fault
   state.
3. Prove independent control of two modules before you change the pattern engine.
4. Add protocol v2 and dual-version UI support.
5. Integrate the LRA driver behind the existing haptic and pattern boundary.
6. Run the complete physical acceptance gate. Record the measured results in a
   bench-test note before you treat the upgrade as done.

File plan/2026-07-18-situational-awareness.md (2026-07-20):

# Bus-Stop Movement Safety and Situational Awareness — Implementation Plan

> **For agentic workers:** REQUIRED SUB-SKILL: Use superpowers:subagent-driven-development (recommended) or superpowers:executing-plans to implement this plan task-by-task. Steps use checkbox (`- [ ]`) syntax for tracking.

**Goal:** Build a two-phase sensing, classification, relay, and output-pattern prototype for a wrist-worn DeafBlind navigation and situational-awareness product. The demo covers local obstacle/siren awareness and camera-guided person avoidance while moving, plus bus arrival, route identification, and guidance toward the bus while still. The intended product uses purpose-built vibration motors; the hack hardware uses two passive buzzers only as audible proxies for those future vibration channels.

**Architecture:** Three sensor inputs and two simulated output channels. A PDM microphone feeds an on-device FFT that fires a shape-aware coarse local alert after about 0.5 s and a confirmed-siren classification after at least 1.02 s. A VL53L0CX ToF gives a purely local proximity reflex with no network in the path. A phone browser POSTs frames at 2 Hz to a Modal endpoint that runs YOLO26n, holds two seconds of detection history, latches exactly one `BUS_ARRIVED` event, and identifies person boxes. Claude reads the bus blind and, only while `MOVING`, judges the clear side around the selected person under strict JSON schemas. Camera submission remains active independently of activity state. The relay exposes `STILL`/`MOVING`; the ESP32 receives directional commands in both known states but renders bus-arrival and route-reading output only while `STILL`. P1 at 2350 Hz and P3 at 3050 Hz audibly simulate two future vibration channels. See the latest Revision note below.

**Tech Stack:** ESP32-S3-MINI-1 (Arduino-ESP32 3.x / ESP-IDF v5.x, FreeRTOS, LEDC in **tone** mode, I2S0 PDM→PCM, `arduinoFFT<float>`, `Adafruit_VL53L0X`, `ArduinoJson` v7) · 2× AX22-0018 passive buzzer (MLT-8530) as audio proxies, not haptic actuators · Modal 1.5.2 + Ultralytics YOLO26n on T4 · `anthropic` 0.117.0 with `output_config.format` structured outputs · Next.js 16.2.10 on Vercel + Upstash Redis · in-browser `getUserMedia` capture on the phone (Python/OpenCV survives only inside Modal, not on a laptop) · build123d via `cad/tests/fake_adsk` for CAD.

**Evidence legend.** Every measured claim below traces to one of four audit files. They are authoritative over anything else in the repository.

| Tag | File |
|---|---|
| **T1** | `audit/situational-awareness/01-track-1-physical-cad-ground-truth.md` |
| **T2** | `audit/situational-awareness/02-track-2-modal-claude-grounding-and-hardcoded-spec.md` |
| **T3** | `audit/situational-awareness/03-track-3-transcript-and-gesture-vocabulary.md` |
| **T4** | `audit/situational-awareness/04-track-4-system-firmware-architecture.md` |
| **T5** | `audit/situational-awareness/05-buzzer-bench-test.md` |

`plan/archive/` holds three superseded plans. **Do not build from them.** Their headers list claims that these four tracks disproved.

---

## Revision 2026-07-19g — Stop-to-direction arbitration

This revision supersedes every older statement that all local proximity output always outranks every cloud direction. Post-demo evidence is recorded in `audit/situational-awareness/27-post-demo-navigation-arbitration.md`.

**1. ToF warns first; camera guidance resolves the bypass.** While `MOVING`, active ToF proximity produces the repeated both-channel stop/obstacle cadence. A fresh camera-derived LEFT or RIGHT then suspends only the ToF output, inserts a 150 ms all-off clearing gap, plays the one-sided direction pattern, inserts another 150 ms clearing gap, and resumes proximity automatically if the obstacle remains in range. ToF sampling never stops.

**2. AHEAD never contradicts local proximity.** AHEAD means the path or target is centered and clear enough to continue. It is accepted for bus guidance in either known activity phase, but it cannot interrupt an active ToF warning. Person avoidance while an obstacle is present produces LEFT or RIGHT, never AHEAD.

**3. Siren remains absolute priority.** Any active siren output cancels a pending or playing cloud direction. Emergency stop, activity changes, and a relay `NONE` edge also cancel a pending direction cleanly.

**4. The grammar is intentionally sequential.** The learnable sequence is `STOP -> silence -> LEFT/RIGHT -> silence -> STOP if still blocked`. Bus alignment while `STILL` remains `LEFT`, `RIGHT`, or `AHEAD` with ToF output suppressed by the activity rule.

---

## Revision 2026-07-19f — Learnable cue grammar and fail-closed person avoidance

This revision supersedes Revision 2026-07-18e wherever that revision cuts camera-guided navigation, and supersedes older one-channel PROXIMITY, WAIT, ERROR, and AHEAD waveforms. The detailed approved contract is `docs/superpowers/specs/2026-07-19-accessible-cue-and-person-guidance-design.md`; implementation evidence is in `audit/situational-awareness/26-accessible-cue-and-person-guidance.md`.

**1. One channel always means a movement direction.** P1-only means move LEFT. P3-only means move RIGHT. No status, hazard, waiting, or error cue may use exactly one channel. AHEAD is one sustained 600 ms pulse on both channels.

**2. Person avoidance is MOVING-only and fail-closed.** With no bus target, the phone selects the highest-confidence person box and sends that normalized box with the frame to `/api/person-direction`. Claude may return only a high-confidence LEFT/RIGHT recommendation, a clear result, or unavailable. Invalid input, malformed output, low confidence, timeout, and model failure produce no direction; none may become AHEAD.

**3. Async results cannot outlive their scene.** The phone aborts and clears person guidance on STILL, bus priority, person disappearance, camera stop, or a tracked-person change. A same-target refresh advances the generation and clears guidance if it fails. The first side applies immediately; reversing LEFT to RIGHT or RIGHT to LEFT requires two consecutive matching Claude results.

**4. Bus direction remains available in both known activity states.** The user may scan for and approach the bus while STILL or MOVING. Existing bus-information precedence and the relay wire contract remain unchanged.

**5. Non-directional cues use both channels.** PROXIMITY is a 120 ms both-channel pulse with the existing distance-mapped cadence. WAIT is `200 on / 600 off / 200 on` on both channels. ERROR is both-channel long-short-long. These changes improve semantic consistency; they do not establish tactile efficacy or DeafBlind-user validation.

---

## Revision 2026-07-18e — Two-phase demo and ESP-side camera-command gate

> **Historical revision. Revision 2026-07-19f supersedes its navigation cut and cue-channel rules.** Its ESP-side bus-information gate and local-sensing phase rules remain current.

This revision supersedes Revision 2026-07-18d's camera-guided LEFT/RIGHT/AHEAD scope and Revision 2026-07-18b's navigation experiment. The implemented experimental direction patterns may remain as dormant provenance, but they are not relay inputs, demo steps, or validated navigation.

**1. The demo has two phases, not two kinds of navigation.** `MOVING` demonstrates supplementary local awareness on the way to the bus stop: ToF forward-clearance feedback plus local siren detection. The cane remains the primary mobility aid and the user chooses how to negotiate an obstacle. `STILL` demonstrates bus-stop situational awareness: BUS, WAIT, route NUMBER, UNKNOWN, and ERROR. The prototype does not guide the user toward the stop, around an obstacle, toward a detected bus, or toward a bus door.

**2. Camera transport stays live.** The phone camera preview and the existing 2 Hz phone-to-Modal submission path may remain active while `MOVING`. Do not modify or pause that pipeline from the board workstream. The ESP32 continues polling, parsing, and advancing command sequence state in both phases.

**3. The ESP32 gates output after reception.** While `MOVING`, camera-derived BUS, WAIT, NUMBER, and UNKNOWN commands are received and sequence-acknowledged but suppressed before output arbitration. While `STILL`, a fresh command may render. A command suppressed while moving is never replayed merely because activity later changes to still.

**3a. Local sensing is state-aware without becoming network-dependent.** ToF sampling remains local and continuous for diagnostics, but its proximity output is permitted only in `MOVING`; entering `STILL` clears it so people and street furniture near a bus stop do not produce a nuisance alert. Siren detection and output remain local and active in both phases.

**3b. Route 88 is guarded on the board.** The P6 waveform is hardcoded to mean route 88. A `NUMBER` command whose wire `route` is not exactly `"88"` or whose `conf` is not `"high"` is consumed without playing P6. This prevents a different or low-confidence reading from producing a confident false route-88 signal.

**4. Activity and command edges are independent.** `/api/pull` exposes activity plus separate activity freshness/version fields. An activity heartbeat must not increment command `seq` or refresh a previous command's `ts`, because doing either could re-fire or make stale bus information appear fresh. Missing, invalid, or stale activity closes the bus-information output gate unless service Serial explicitly controls the bench test.

**5. Demo order is locked.** Start in `MOVING`; demonstrate a ToF obstacle and then a siren. Switch to `STILL`; only then introduce the printed bus prop and deliver a fresh BUS → WAIT → NUMBER 88 sequence. The bus prop must not latch an arrival before the still transition unless the web producer explicitly resets/re-arms it.

**6. Two output channels do not imply sensed directionality.** The single approximately 25-degree forward ToF zone cannot determine whether left or right is traversable. During the obstacle step, the user and cane choose the bypass; the ToF pulse cadence slows and stops as the forward zone clears. Existing P1/P3 LEFT/RIGHT service tones may be shown separately as a conceptual future-channel simulation, but they are not relay commands and must not be described as an automatic obstacle-avoidance decision. Automated bypass guidance requires at least two independently aimed spatial zones or a validated depth/free-space model, plus real actuators and representative-user testing.

---

## Revision 2026-07-18d — Navigation state and buttonless four-slot interaction

> **Historical revision. Revision 2026-07-18e supersedes its LEFT/RIGHT/AHEAD and bus-approach guidance.** Its four-slot hardware and buttonless boot decisions remain current.

This revision previously made navigation a first-class feature rather than an appendix to bus-stop awareness.

**1. The interaction model has two explicit states.** `STILL` is the waiting state: bus-arrival, route-reading, WAIT, and UNKNOWN commands are accepted. `MOVING` is the approach state: LEFT, RIGHT, and AHEAD commands are accepted as coarse guidance toward the detected bus/door target. Local ToF proximity and siren processing stay active in both states and always outrank cloud commands.

**2. The phone owns movement state.** For the hack, the capture UI exposes a manual `STILL`/`MOVING` control and may later derive the same field from phone motion sensors. The board does not have an IMU and must not guess movement from ToF. The relay contract carries the state with each command; missing state defaults to `STILL` for backward compatibility.

**3. Do not spend a module slot on a button.** The locked port map remains P1/P3 outputs, P2 ToF, P4 PDM microphone. The full firmware boots operationally without arming. USB-C remains power, flashing, and service Serial for this hack; phone-originated runtime control uses the already-built HTTPS relay, avoiding a second transport. The onboard user button may become a physical fallback only after its GPIO and polarity are bench-verified; no core workflow may depend on it.

**4. Keep the team boundary explicit.** Camera/Modal workers produce arrival, route, target direction, and phone activity state. Board workers implement local sensing, arbitration, output patterns, command parsing, staleness handling, and the interaction-state gate. Both sides meet at the contracts below.

---

## Revision 2026-07-18c — Buzzer tactile failure and audio-proxy demo

This revision supersedes every downstream statement that describes the AX22-0018 modules as felt, tactile, haptic, or accessibility-validating output.

**1. The tactile viability test failed.** The labelled 70/100/150/220 Hz sweep was audible but produced virtually no tactile movement [T5]. The AX22-0018 modules are rejected as haptic actuators for this prototype. Do not continue the blind tactile-discrimination test and do not describe the current output as haptic feedback.

**2. The hack demo now uses an explicit audio simulation.** P1 plays 2350 Hz and P3 plays 3050 Hz. This preserves the original 700 Hz separation while moving both tones close to the MLT-8530's 2.7 kHz resonance for better audibility in a noisy room. Patterns designated BOTH play both channel frequencies; patterns designated A or B remain on their assigned channel; alternating patterns alternate them. This preserves output routing, count, rhythm, duration, and semantic integration for demonstration, but proves nothing about tactile perception or spatial localization.

**3. Product direction still assumes real vibration hardware.** A future build would replace both buzzers with purpose-built ERM or LRA actuators and adapt the vocabulary to their actual amplitude and waveform controls. That is a documented product assumption, not a current result. It remains unvalidated until tested on real actuators with representative users.

**Stage line:** *"These two tones simulate the two vibration channels the product would use. The supplied buzzers could be heard but not felt, so this prototype demonstrates sensing and pattern routing rather than tactile efficacy."*

---

## Revision 2026-07-18b — Actuator swap, mobile capture, L/R navigation attempt

> **Historical revision. Revision 2026-07-18c supersedes its tactile and wear-test proposals; Revision 2026-07-18e supersedes its LEFT/RIGHT/AHEAD proposal.** Its camera-host and electrical facts remain current.

This revision overrides earlier rulings where they conflict. Three changes, all landing after the first four audit tracks were written. Downstream mentions must now also be read through Revision 2026-07-18c and T5.

**1. The two ERM motors are replaced by two AX22-0018 passive buzzers.** The ERMs could not be sourced in time; the buzzer ships in the Genesis Mini Starter Kit and is in hand. It is an **MLT-8530 electromagnetic** (magnetic, not piezo) transducer on a 22×22 mm module — 2.7 kHz resonant, 80 dB — driven by a **single Signal-pin PWM** (header `G / Vin / S`); there is no second drive channel and no amplitude-by-duty knob the way an ERM has [`parts/Axiometa Genesis Mini - Starter Kit/passive-buzzer/CONTENT.md`]. This flips the drive model from *duty-cycle amplitude* to *frequency (tone)* and flips the output physics from inertial vibration to acoustic diaphragm motion. **We drive the buzzer at a low frequency to elicit a felt buzz rather than an audible tone.** This is an experiment: a sealed magnetic buzzer is not a tactile actuator, so the felt output may be weak. A first-hour wear test (Task 13-adjacent) decides whether the tactile path is viable or whether the device falls back to audible-tone signalling for a hearing companion. The overdrive-kick / start-voltage analysis written for the ERM is **moot** — buzzers have no stiction and no inrush.

**2. Camera capture moves from the laptop Python client to the mobile-ready `app/` app.** [T4 §Decision 1] locked `cv2.VideoCapture(0)` on the laptop and explicitly rejected a browser app; that ruling is **reversed by request.** George owns the Next.js app in `app/`; its capture page uses `getUserMedia({ video })` + a `<canvas>` grab at 2 Hz and is served over HTTPS on the Vercel deployment. `vision/bus_client.py` is **cut**; `vision/bus_vision.py` (Modal) and `vision/read_blind.py` remain. The trade [T4 §Decision 1] warned of — iOS Safari permission UX, a possible reload-and-re-grant on stage — is now **accepted, not avoided**; rehearse the grant flow before the demo.

**3. Left/right navigation is back in scope as software and audio simulation.** [T3 D14/D20] cut LEFT/RIGHT/AHEAD and retired all spatial coding because the two ports are a fixed 33.941 mm apart — below the ~70 mm forearm two-point threshold. **That geometry is unchanged by the swap** and spatial localization stays unavailable. The current demo carries LEFT/RIGHT through a per-channel audio contrast: 2350 Hz on P1 and 3050 Hz on P3. P11–P13 validate navigation command routing only. Future motors require a new tactile vocabulary and wear test; no current result predicts their discriminability.

---

## Global Constraints

Every task's requirements implicitly include this section.

1. **Today is 2026-07-18. The hack ends 2026-07-19. Roughly 1.5 days remain.** Sequencing beats completeness. The Cut List near the end is binding when the clock runs out.
2. **Hardcoding is sanctioned.** Route **88**, destination **Clapham Common**. No configuration knobs, no generality, no "make this pluggable".
3. **No soldering. All modules are AX22 snap-in. No extension kit, no ribbon leads, no purchased extras.** All four ports are occupied and every part is in hand.
4. **The two buzzers are audio proxies, not tactile actuators** [T5]. P1 uses 2350 Hz and P3 uses 3050 Hz to make the two conceptual channels audible. Their 33.941 mm physical separation carries no validated directional meaning in the current demo. Do not claim spatial or tactile left/right discrimination.
5. **Buzzer Signal pins drive from Port 1 and Port 3.** The AX22-0018 header is `G / Vin / S` — a single Signal line per buzzer plus power and ground; there is no second drive channel. Working assumption: Signal → **GPIO3 (Port 1)** and **GPIO16 (Port 3)**, reusing the ERM diagonal. **Confirm the Signal-pin-to-IO mapping against `parts/Axiometa Genesis Mini - Starter Kit/passive-buzzer/files/SCH_AX22-0018.pdf` and the module silk before first drive** — it was derived for the ERM (AX22-0013), not this part. The committed `firmware/braille_wearable/src/pins.h:9-10` says GPIO4/GPIO9 and is **wrong** for either part; with those pins nothing sounds and it looks like dead hardware.
6. **The microphone binds to `I2S_NUM_0`. Never `I2S_NUM_1`, never `I2S_NUM_AUTO`.** The PDM-to-PCM converter exists on I2S0 only, and binding I2S1 fails silently by yielding a raw bitstream [T3 §PDM capture, T4 §TRAP 1].
7. **The ToF → output reflex and siren → output reflex are fully local.** No network in either path. ToF output is enabled only in `MOVING`, while siren output remains enabled in both phases. In the hack demo the output is an audible proxy; the product intent is local vibration output.
8. **Power: a ≥1 A (≥5 W) USB-C source — kept for margin, but its old binding reason is gone.** That constraint was 2 × ERM inrush [T1 §Old Global Constraints row 3]. Two MLT-8530 buzzers draw on the order of ~30 mA each with no inertial inrush, so the rail is comfortable now; ESP32-S3 + Wi-Fi transients dominate. Keep ≥1 A anyway — headroom is free.
9. **The ESP32 is outbound-only.** It polls `https://tacta.space/api/pull` every 300 ms and never accepts an inbound connection.
10. **Serverless is stateless; all shared state lives in Upstash Redis.** The one exception is the Modal container's own arrival state machine, which is safe only because `max_containers=1` pins it to a single process.
11. **Pin versions exactly for isolated hardware runners:** `adafruit/Adafruit_VL53L0X@1.2.5`. The integrated dependency set remains `modal==1.5.2`, `anthropic==0.117.0`, `kosme/arduinoFFT@^2.0.4`, `bblanchon/ArduinoJson@^7.4.3`, `next@16.2.10`, `@upstash/redis@^1.38.0` until its lockfiles are refreshed deliberately.
12. **Use Anthropic's first-class structured outputs** (`output_config.format` + `json_schema`). Prompt-only JSON is the weakest available mechanism and **assistant prefill now returns 400** on Opus 4.8 [T2 §Claude Vision 3].
13. **"We have not validated with DeafBlind users."** That sentence survives into every artefact, unchanged. The community norm is "nothing about us without us". The transcript's *"we've talked to them"* is genuinely ambiguous [T3 D15] and **no claim may be built on it**.
14. **`parts/` is a catalogue mirror, not an inventory.** Absence of a folder is evidence about Axiometa's product listing and says nothing about what is on the bench [T1 §Inference trap].
15. **The current buzzer output is audible demo feedback, not a DeafBlind-accessible output channel.** A companion/debug screen provides ground truth. Product accessibility depends on replacing the buzzers with validated vibration hardware.
16. **No external button module.** All four ports are committed to two output channels, ToF, and PDM microphone. The phone is the primary interaction surface; the onboard button is an optional fallback only after bench verification.

---

## Do This First

**Three things block everything else and all three are unattended waiting. Start them before you read another line.**

### 1. The PlatformIO toolchain — the longest-lead item in the build

`firmware/braille_wearable/platformio.ini:18` pins `default_envs = genesis_mini_offline`, which resolves to `espressif32@7.0.1` → Arduino-ESP32 **2.0.17** → ESP-IDF **v4.4.7**. **`driver/i2s_pdm.h` does not exist in v4.4.7** — the raw GitHub path 404s — so **the siren feature cannot compile at all** in the default environment [T4 §Build Mechanics]. The build must move to `env:genesis_mini` (Arduino 3.3.x → ESP-IDF v5.5.x), whose platform is **not cached on this machine** (`~/.platformio/platforms/` contains only `espressif32` and `native`). First build downloads platform + core + GCC-14, roughly **1 GB**.

```bash
cd /Users/haidertoha/Code/axiometa-ant-hack/firmware/braille_wearable
pio run -e genesis_mini
```

Expected: a long download, then `SUCCESS` with a RAM/Flash summary. Run it **now, on good wifi**, in a background terminal. It does not need the board attached.

| Arduino-ESP32 | ESP-IDF | `driver/i2s_pdm.h` | LEDC API |
|---|---|---|---|
| 2.0.17 (current `default_envs`) | v4.4.7 | ❌ legacy `driver/i2s.h` only | `ledcSetup` + `ledcAttachPin` |
| 3.3.x (`env:genesis_mini`) | v5.5.x | ✅ | `ledcAttach(pin, freq, bits)` |

**Contingency if the download fails at the venue:** build the siren tier against the legacy `driver/i2s.h` API (`I2S_MODE_PDM` + `i2s_set_pdm_rx_down_sample(I2S_NUM_0, I2S_PDM_DSR_8S)`), which does work on 2.0.17. That costs an afternoon of API translation. Downloading tonight costs twenty minutes of waiting.

### 2. Modal billing — a two-minute task that can cost an hour at 3 a.m.

Modal's own documentation states verbatim: *"Note that you must have a payment method on file in order to use Modal."* Third-party blogs claim Starter needs no card; **Modal's docs are the authority and they contradict them** [T2 §Modal 2].

```bash
pip install "modal==1.5.2"
modal setup                     # browser auth
modal secret create anthropic ANTHROPIC_API_KEY="$ANTHROPIC_API_KEY"
```

Then open https://modal.com/settings/billing and confirm a payment method is listed. Expected: a card on file, Starter plan, `$30 / month free credits`.

### 3. Calipers on the microphone — 60 seconds, two answers, both load-bearing

**AX22-0044 (marking T3902) is in hand.** It has no folder under `parts/` because it is a new product not yet on the Axiometa catalogue — uncatalogued, not absent [T1 §Inference trap]. There is no STEP file, so two dimensions cannot be measured from CAD and must be measured with calipers and eyes:

- **Z height above its own module PCB top.** Available headroom is **4.64 mm** (deck inner face +16.25 minus module PCB top +11.61) [T1 §Derived mated stack]. The ERM uses 3.685 mm. **The tallest non-encoder module in the AX22 family, the DHT11, is 5.835 mm** — so a collision is plausible, not hypothetical. If the mic exceeds 4.64 mm, raise `Z_ROOF_INNER` and `Z_ROOF_OUTER` in `cad/braille_wearable_enclosure.py` by the difference and recompute the ToF aperture for the larger air gap.
- **Whether the MEMS port is top- or bottom-firing.** All 10 measured AX22 modules place their functional component on the +Z face, so **top-firing is much more likely — but that is an inference from other modules, not a measurement of this one** [T1 §Microphone Acoustic Port]. Top-firing → a Ø3.0 hole through the deck at (−12, +12). Bottom-firing → that hole does nothing and the interior must be vented instead.

Write both answers into this plan's Task 16 before the print starts.

### 4. Start the print as soon as Task 16's STL exists

37.01 cm³ measured, ~3–4.5 h estimated (not sliced). **Black or dark filament, 10–15 % infill.** Dark filament for bore-wall IR absorption at the ToF aperture; low infill matters even more now — a passive buzzer's felt output is already weak, so **the enclosure must not damp it**. Keep the P1 open-reveal well so buzzer A couples directly to the wrist, and treat the P3 louvre grille as the vent for the audible fallback. This is machine time, not person time — it runs while firmware is written. [T1 §Three caveats, amended by Revision §1]

---

## Asset Inventory

### Hardware — **there are no GAP items**

Earlier drafts assumed a missing microphone. That assumption was wrong, and its correction is what makes the four-port map complete.

| Asset | Status | Notes |
|---|---|---|
| Axiometa Genesis Mini (ESP32-S3-MINI-1-N4R2) | **REUSE / IN-HAND** | 55.000 × 55.000 mm PCB, MEASURED-FROM-STEP [T1] |
| VL53L0CX ToF, AX22-0015 | **REUSE / IN-HAND** | `parts/distance-sensor-vl53l0cx/files/AX22-0015.step` |
| ~~ERM vibration motor ×2, AX22-0013~~ | **CUT — could not source in time** | Superseded by the buzzer below (Revision §1) |
| **Passive buzzer ×2, AX22-0018 (MLT-8530)** | **REUSE / IN-HAND** | `parts/Axiometa Genesis Mini - Starter Kit/passive-buzzer/`. 22×22 mm module, single Signal-pin PWM. Bench-rejected as tactile actuators; retained as 2350/3050 Hz audio proxies [T5] |
| **PDM microphone, AX22-0044, marking T3902** | **REUSE / IN-HAND** | **No `parts/` folder, no STEP, no public product page — new uncatalogued hardware.** Footprint is `ASSUMED-AX22-STANDARD`; Z height and port face need calipers (Do This First §3) |
| USB-C source, ≥1 A | **REUSE / IN-HAND** | Constraint 8 |
| 20 mm strap + Ø2.5 pins | **REUSE / IN-HAND** | Drives `LUG_GAP = 20.0`, not 22.0 |
| FDM printer + dark filament | **REUSE / IN-HAND** | Task 16 |
| **Phone with rear camera + modern browser** | **REUSE / IN-HAND** | The camera host (Revision §2). Runs the `getUserMedia` capture page over HTTPS; replaces the laptop webcam. Needs the venue Wi-Fi/hotspot, nothing installed |
| A3 bus-front print **or** an 11–13″ tablet | **NET-NEW** | Task 17. Build the tablet version first — it needs no printer |
| Calipers | **REUSE / IN-HAND** | 60 seconds of work, two load-bearing answers |

**No GAP items in hardware.** Every port is populated, nothing needs sourcing, nothing needs soldering.

### Firmware — `firmware/braille_wearable/`

The directory keeps its legacy name to avoid churning PlatformIO paths. Nothing inside it will be about braille when Task 2 finishes.

| Path | Verdict | Detail |
|---|---|---|
| `platformio.ini` | **REUSE (modify)** | `default_envs` → `genesis_mini`. Keep `-DARDUINO_USB_MODE=1` / `-DARDUINO_USB_CDC_ON_BOOT=1` (:33-34) — hard-won and still correct. Keep `[env:native]` (:75-78) unchanged; it is the TDD asset |
| `src/net.cpp` · `src/net.h` | **REUSE (modify) — the most valuable software asset in the repo** | `wifiJoin()` (`net.cpp:14-31`) keep verbatim including `setInsecure()` (:27); keep the `seq` gate (:54-56) and the v7 `JsonDocument` (:50); `postReply()` (:67-84) is the template for `/api/event` |
| `src/pins.h` | **REUSE (modify) — contains a bug** | `MOTOR_L 4` / `MOTOR_R 9` → `3` / `16` |
| `src/secrets.h` | **REUSE unchanged** | Committed template; `.gitignore:5-6` already ignores the real one |
| `src/braille_wearable.cpp` | **REUSE (~20 %)** | `setup()` ordering (:71-91) and `repeatPressed()` (:58-69, a correct active-high GPIO45 debounce) survive; everything else goes |
| `src/braille.cpp` · `src/braille.h` | **DELETE** | **Not adaptable.** `beat()`/`buzzLetter()`/`buzzWord()` are a `delay()` chain that blocks the MCU for up to ~48 s. There is no state machine to adapt. **Only the five timing constants at `braille.cpp:12-16` survive** — 400 / 300 / 800 / 1500 / 100 ms |
| `src/display.cpp` · `src/display.h` | **DELETE** | Out of BOM; Port 2 reallocated to the ToF |
| `src/encoder.cpp` · `src/encoder.h` | **DELETE** | Out of BOM; Port 4 reallocated to the microphone |
| `test/test_braille/` | **DELETE (content) / REUSE (technique)** | It proves `[env:native]` works and demonstrates re-deriving the table under test rather than copying it (`:33-48`). Mirror that technique |
| `src/haptic_pure.h` | **NET-NEW** | Arduino-free sequencer + arbitration. Host-testable |
| `src/haptic_route_pure.h` | **NET-NEW** | Quinary route encoder. Host-testable |
| `src/patterns.h` | **REUSE** | The 11 demo pattern tables are current. The already-implemented P11–P13 direction experiments are dormant provenance and must not be exposed through the relay or demo controls. Each step is a `(freq, on/off)` pair, not a duty. Host-testable |
| `src/siren_pure.h` | **NET-NEW** | Siren decision logic over a magnitude array. Host-testable |
| `src/haptic.cpp` · `src/haptic.h` | **NET-NEW** | LEDC **tone** glue (`ledcAttach(pin, freq, res)` + `ledcWriteTone(pin, hz)`, or `ledcWrite` at 50 % duty for a given freq) + `hapticTask`. No duty-amplitude control — steps set a frequency or 0 |
| `src/audio.cpp` · `src/audio.h` | **NET-NEW** | I2S0 PDM capture + FFT + `audioTask` |
| `src/tof.cpp` · `src/tof.h` | **NET-NEW** | VL53L0X continuous ranging |
| `src/main.cpp` | **NET-NEW** (from `braille_wearable.cpp`) | `setup()` + `loop()` = ToF and button only |

### Web app — `app/` (George-owned; do not edit from the board workstream)

| Path | Verdict | Detail |
|---|---|---|
| `app/src/lib/redis.ts` | **REUSE (implemented)** | Preserve the **MSET-before-INCR** ordering. It prevents readers from observing a new sequence with the previous payload |
| `app/src/app/api/pull/route.ts` | **REUSE (implemented)** | Outbound board polling plus telemetry; preserve no-store/CORS behavior |
| `app/src/app/api/event/route.ts` | **REUSE (implemented)** | Sanitises camera-derived bus commands and writes relay state; do not add direction commands |
| `app/src/lib/contract.ts` | **REUSE (implemented)** | Independent `UserActivity`, `activitySeq`, and `activityTs` fields plus the nine-value cloud command vocabulary |
| `app/src/app/page.tsx` | **REUSE (implemented)** | Device/relay monitor |
| `app/src/app/capture/page.tsx` | **REUSE for capture/Modal submission** | Existing camera host remains active in both phases. A separate activity setter may be added, but do not gate frame submission or translate target bearing into device commands |
| `app/package.json` · `app/pnpm-lock.yaml` | **REUSE** | Active Next.js 16 dependency surface |
| Vercel project link + Upstash env | **REUSE unchanged** | `haider-projects/bus-stop-awareness`, production domain `tacta.space`, `UPSTASH_*` already set at Production scope |
| `app/src/app/api/state/route.ts` · `api/detector/route.ts` | **REUSE (implemented)** | Debug-screen state surfaces |

### Vision — `vision/` (net-new directory)

| Path | Verdict |
|---|---|
| `vision/bus_vision.py` | **NET-NEW** — the Modal app |
| ~~`vision/bus_client.py`~~ | **CUT (Revision §2)** — laptop capture replaced by `app/src/app/capture/page.tsx` |
| `vision/read_blind.py` | **NET-NEW** — standalone Claude call, developed and timed before it is pasted into Modal |
| `vision/requirements.txt` | **NET-NEW** |

### CAD — `cad/`

| Path | Verdict | Detail |
|---|---|---|
| `cad/braille_wearable_enclosure.py` | **REUSE (modify) — the chosen design** | Ten one-line deletions produce a closed body in 0.24 s. **Also reconcile `MOTOR_TOP = 15.25` (ERM body top) with the AX22-0018 buzzer height measured from `parts/.../passive-buzzer/files/AX22-0018.step`** — if the buzzer module is taller, raise `Z_ROOF_INNER`/`Z_ROOF_OUTER` by the difference; the 22×22 mm footprint is unchanged (Revision §1) |
| `cad/tests/test_enclosure_build.py` | **REUSE (modify)** | Update two lug-bore probes and add two aperture probes |
| `cad/tests/fake_adsk/` | **REUSE unchanged** | A real build123d engine, not a stub. **Fusion 360 is not required for anything in this plan** |
| `cad/braille_wearable_exocage.py` | **LEAVE ALONE** | Not used. Do not edit it; its `POST_INNER = 22.0` is a trap (see Task 16) |

---

## Port Map

Port centres are **MEASURED-FROM-STEP** (`parts/Axiometa Genesis Mini - Starter Kit/axiometa-genesis-mini/files/STP_MTX0013.step`, socket-pair centroids, max deviation 0.001 mm) [T1].

| Port | Centre | Module | Signal |
|---|---|---|---|
| **P1** | (−12.000, −12.000) | **Buzzer A (left)** | Signal = **GPIO3** (verify vs SCH_AX22-0018) |
| **P2** | (+12.000, −12.000) | **VL53L0CX ToF** | SDA = GPIO10, SCL = GPIO11 (shared bus) · XSHUT = IO1 = GPIO6 |
| **P3** | (+12.000, +12.000) | **Buzzer B (right)** | Signal = **GPIO16** (verify vs SCH_AX22-0018) |
| **P4** | (−12.000, +12.000) | **PDM microphone (AX22-0044)** | CLK = **GPIO18**, DT = **GPIO17**, SL = **GPIO1 high**. Bind to **I2S0**, `I2S_PDM_SLOT_RIGHT` |

- Diagonals are **{1,3}** and **{2,4}**. P1↔P3 = **33.941 mm**; P1↔P2 = 24.000 mm (adjacent). Buzzers take the diagonal for maximum separation — which still falls short of spatial two-point discrimination, so L/R rides on the per-side frequency contrast, not this distance.
- ToF I²C address is **0x29 (7-bit)** / 0x52 (8-bit write), fixed in silicon. One sensor, no collision. XSHUT is not required for single-sensor operation. `SCH_AX22-0015.pdf` labels XSHUT `IO1D`; on P2 that is GPIO6. This corrects the earlier IO0/GPIO7 inference.
- **The PDM pin assignment was verified from the installed module silk on 2026-07-18.** The header order is `G / 3V3 / SL / DT / CLK`. Board connector pins 3/4/5 are IO0/IO1/IO2, giving SL GPIO1, DT GPIO17, and CLK GPIO18 on P4. The evidence is the user-provided bench photograph `IMG_0195.HEIC` plus `SCH_MTX0013.pdf`; no pin assignment is inferred from the missing catalogue folder.
- Pin choice is otherwise free: ESP32-S3 routes I²S through the GPIO matrix, so any of GPIO1/17/18 can carry either signal. **The peripheral choice is not free — it must be I2S0.**

---

## Data Contracts

Four contracts, all literal, all worked with route 88.

### Contract A — phone → Modal

```jsonc
// POST https://<workspace>--bus-vision-ingest.modal.run
{ "frame_b64": "/9j/4AAQSkZJRgABAQAAAQ…9k=",   // ~120 kB base64 of a 1280×720 q85 JPEG
  "force": false }                              // true only for the disclosed SPACE key
```

```jsonc
// 200 response
{ "event": "BUS_ARRIVED",        // "NONE" | "BUS_ARRIVED" | "BUS_GONE"
  "present": true,
  "confidence": 0.83,            // best bus-box confidence this frame
  "arrival_id": 1,               // increments once per arrival — the fire-once latch
  "reading": null,               // null until Claude answers
  "reading_ready": false,
  "votes": [] }                  // Claude's raw route strings once it has answered
```

**The frame-by-frame walk, literally.**

```jsonc
// frame N   — nothing in view
{"event":"NONE","present":false,"confidence":0.0,"arrival_id":0,
 "reading":null,"reading_ready":false,"votes":[]}

// frame N+1 — prop raised, first detection, NOT enough evidence yet
{"event":"NONE","present":false,"confidence":0.71,"arrival_id":0,
 "reading":null,"reading_ready":false,"votes":[]}

// frame N+2 — second consecutive detection, LATCH FIRES
{"event":"BUS_ARRIVED","present":true,"confidence":0.83,"arrival_id":1,
 "reading":null,"reading_ready":false,"votes":[]}

// frame N+7 — ~2.5 s later, three concurrent Claude votes have returned
{"event":"NONE","present":true,"confidence":0.85,"arrival_id":1,
 "reading":{"route":"88","destination":"Clapham Common","confidence":"high"},
 "reading_ready":true,"votes":["88","88","88"]}
```

### Contract B — phone browser → Vercel

The **browser capture page** is now the only component that understands both the detector's vocabulary and the device's (Revision §2 — it inherits this role from the cut laptop client). It translates Modal's detector response into a `CloudPattern`, and it POSTs to `/api/event` **only on change** — the relay is edge-triggered on `seq`, so re-posting an unchanged state would re-fire the haptic. (Alternatively Modal POSTs to `/api/event` directly; keep it in the browser so the one component that speaks both vocabularies also owns the edge-trigger.)

```ts
// app/src/lib/contract.ts — shared browser/API contract
export type PatternId =
  | "NONE"      // no active command
  | "READY"     // P0  boot complete
  | "DANGER"    // P1  confirmed siren, amplitude rising   (device-local; never sent)
  | "SIREN"     // P2  confirmed siren, flat or falling    (device-local; never sent)
  | "ATTENTION" // P3  Tier-2a band-energy alert           (device-local; never sent)
  | "PROXIMITY" // P4  ToF advisory                        (device-local; never sent)
  | "BUS"       // P5  bus arriving
  | "NUMBER"    // P6  route number — uses `route`
  | "WAIT"      // P7  request in flight
  | "UNKNOWN"   // P8  could not read / low confidence
  | "ACK"       // P9  button feedback                     (device-local; never sent)
  | "ERROR";    // P10 degraded

/** Cloud-originated commands only. Local safety patterns never cross the wire. */
export type CloudPattern =
  | "NONE" | "LEFT" | "RIGHT" | "AHEAD"
  | "BUS" | "NUMBER" | "WAIT" | "UNKNOWN" | "ERROR";

export type UserActivity = "STILL" | "MOVING";

export interface EventRequest {
  pattern:   CloudPattern;
  route:     string;                 // "" unless pattern === "NUMBER"
  dest:      string;                 // debug screen ONLY — the device ignores this field
  conf:      "high" | "low" | "";
  arrivalId: number;
}

export interface DeviceCommand {
  seq:       number;                 // monotonic; the device's edge-trigger
  pattern:   CloudPattern;
  activity:  UserActivity;
  activitySeq: number;               // advances on transitions and heartbeats
  activityTs: number;                // independent freshness for the activity gate
  route:     string;
  dest:      string;
  conf:      "high" | "low" | "";
  arrivalId: number;
  ts:        number;                 // ms epoch of the server write — staleness check
}

export interface Telemetry {
  bandRms: number; peakHz: number; modIdx: number;
  trend: "rising" | "flat";
  playing: PatternId; tofMm: number; upMs: number; rssi: number;
}

export interface DetectorState {
  event: string; present: boolean; confidence: number; arrivalId: number;
  route: string; destination: string; readingConf: string; votes: string[];
}

export interface DebugState {
  seq: number;
  device: Omit<DeviceCommand, "seq">;
  detector: DetectorState;
  telemetry: Telemetry;
}

/** Route numbers longer than this cannot be delivered inside a bus dwell. */
export const ROUTE_MAX_DIGITS = 3;
/** Quinary encoding covers digits only. A route containing a letter is rejected server-side. */
export const ROUTE_RE = /^[0-9]{1,3}$/;
export const CLOUD_PATTERNS: readonly CloudPattern[] =
  ["NONE", "LEFT", "RIGHT", "AHEAD", "BUS", "NUMBER", "WAIT", "UNKNOWN", "ERROR"] as const;
```

**The locked demo, in order, literally.**

```jsonc
// Before the prop enters frame, activity changes independently to STILL.
// This updates activity/activitySeq/activityTs but does NOT change command seq or ts.

// t = 0.00 s   browser → POST /api/event      (YOLO latched arrival_id 1)
{ "pattern":"BUS", "route":"", "dest":"", "conf":"", "arrivalId":1 }
// ← 200 {"seq":7}

// t = 0.10 s   browser → POST /api/event      (Claude in flight)
{ "pattern":"WAIT", "route":"", "dest":"", "conf":"", "arrivalId":1 }
// ← 200 {"seq":8}

// t = 2.60 s   browser → POST /api/event      (3 concurrent votes agreed on "88")
{ "pattern":"NUMBER", "route":"88", "dest":"Clapham Common", "conf":"high", "arrivalId":1 }
// ← 200 {"seq":9}
```

### Contract C — ESP32 ↔ Vercel

```jsonc
// ESP32 → POST /api/pull  every 300 ms.  Request body = telemetry for the debug screen.
{ "bandRms":312.4, "peakHz":940, "modIdx":0.62, "trend":"rising",
  "playing":"NUMBER", "tofMm":842, "upMs":93000, "rssi":-58 }

// ← 200 response = command state plus independently-versioned activity state.
{ "seq":9, "pattern":"NUMBER", "route":"88", "dest":"Clapham Common",
  "conf":"high", "arrivalId":1, "ts":1784419200123,
  "activity":"STILL", "activitySeq":4, "activityTs":1784419199000 }
```

`GET /api/pull` stays implemented (same handler, empty telemetry) purely so the endpoint remains `curl`-able — that is how the existing relay was smoke-tested and it is worth six extra lines.

What the board actually holds:

```c
// src/net.h — REPLACES struct PullResult (net.h:10-15)
enum : uint8_t { CONF_NONE = 0, CONF_LOW, CONF_HIGH };
enum : uint8_t { ACT_UNKNOWN = 0, ACT_MOVING, ACT_STILL };

struct DeviceCommand {
    long    seq       = 0;
    uint8_t pattern   = PAT_NONE;   // string → enum ONCE, at parse time
    uint8_t activity  = ACT_UNKNOWN; // only fresh ACT_STILL opens bus output gate
    long    activitySeq = 0;
    char    route[8]  = {0};        // "88" · "205" · longest UK route "N550" is 4 chars
    uint8_t conf      = CONF_NONE;
    long    arrivalId = 0;
};                                  // Fixed-size. No String. No vector. No heap.
```

Three deliberate RAM decisions [T4 §Contract C]:

1. **`dest` is parsed and discarded.** It exists for the debug screen; the device has nothing to show it on. Never store it.
2. **`pattern` becomes a `uint8_t` at parse time.** The old `PullResult` kept `String mode` and compared it with `pr.mode == "forward"` — a heap allocation and a `strcmp` three times a second, forever.
3. **`route` is a fixed `char[8]`.** The old `std::vector<String> replies` allocated on every poll. Fixed arrays cannot fragment the heap.

```c
static const size_t PULL_BODY_MAX = 512;   // reject anything larger BEFORE parsing
// Measured: the 108-byte response above deserialises into ~230 bytes of ArduinoJson v7 pool.
```

### Contract D — debug screen

```jsonc
// GET /api/state  — browser only, ~700 B, polled at 500 ms by the Next.js page
{ "seq": 9,
  "device":    { "pattern":"NUMBER","route":"88","dest":"Clapham Common",
                 "conf":"high","arrivalId":1,"ts":1784419200123,
                 "activity":"STILL","activitySeq":4,"activityTs":1784419199000 },
  "detector":  { "event":"NONE","present":true,"confidence":0.85,"arrivalId":1,
                 "route":"88","destination":"Clapham Common","readingConf":"high",
                 "votes":["88","88","88"] },
  "telemetry": { "bandRms":312.4,"peakHz":940,"modIdx":0.62,"trend":"rising",
                 "playing":"NUMBER","tofMm":842,"upMs":93000,"rssi":-58 } }
```

`telemetry` is the ESP32's own state, written to Redis by `/api/pull` on each poll. **This is what makes the siren tier visible to an audience** — without it the FFT is invisible and judges have to take the buzz on faith.

---

## The Output Vocabulary — all patterns time-coded

Two AX22-0018 passive buzzers now render the vocabulary as an **audible simulation** [T5]. P1 uses 2350 Hz and P3 uses 3050 Hz so the two conceptual future vibration channels remain explicit. Pattern semantics still use channel, simultaneity, count, rhythm, and duration, but no result from this hardware validates tactile perception.

> **Post-bench-test interpretation.** These patterns were authored for future vibration motors. On the hack hardware, ignore duty/intensity and render channel A as 2350 Hz and channel B as 3050 Hz. Count, rhythm, duration, and channel routing remain demonstrable. Felt intensity, tactile pitch, and body localization do not.

### Design rules

1. **ONE channel is reserved for direction.** P1-only means LEFT and P3-only means RIGHT. Every non-direction cue uses both channels. P11–P13 are live relay inputs, but provide no evidence that future body-worn actuators will be spatially distinguishable.
2. **BOTH channels mean a non-directional event or AHEAD.** Rhythm separates local hazard, information, waiting, error, and continue-forward meanings. This demonstrates software routing only. The future motor implementation must validate the entire vocabulary with representative users.
3. **Frequency is the primary channel; loudness is not.** Usable design: a **buzz band ≈ 60–120 Hz** and an **alert band ≈ 180–250 Hz**, both felt as coarse "low" vs "high" texture, plus plain on/off gating. Do not design meaning onto fine amplitude steps — the buzzer cannot deliver them.
4. **Proven timing primitives reused, not reinvented** (`firmware/braille_wearable/src/braille.cpp:12-16`): buzz 400 ms · beat gap 300 ms · letter gap 800 ms (reused as the inter-digit gap). The both-fire stagger is retained at 30 ms only for onset legibility, not electrical reasons (see rule 5).
5. **No electrical stagger is needed for the audio proxy.** The buzzers have no ERM inrush, so both tones may start simultaneously. Future vibration hardware must make its own onset and power decision.
6. **Every pattern is a step table** driven by a 10 ms tick. Arbitration is a pointer store; all timing stays off the main loop. Each step now carries a **(freq, on/off)** pair instead of a duty %.
7. **No overdrive kick.** It existed to break ERM stiction on unknown start voltage — a problem buzzers do not have. Onsets are clean; drive straight to the target frequency.

### Driving the passive buzzers as explicit audio proxies

The AX22-0018 is built for audible output — MLT-8530, 2.7 kHz resonant, 80 dB [`passive-buzzer/CONTENT.md`]. The bench test confirmed that it could be heard but not practically felt [T5]. The demo therefore drives P1 at 2350 Hz and P3 at 3050 Hz. These tones preserve the original 700 Hz separation while sitting close to resonance, making channel selection more audible without pretending to reproduce the physics of ERM/LRA vibration.

There is no buzzer datasheet risk of the ERM kind — the MLT-8530 part is named on the product page and the LCSC datasheet (C94599) is the real PDF, not an HTML scrape. The uncertainty here is **perceptual**, and only a wrist can resolve it.

### The locked table

Notation: `A` = Port 1 buzzer, `B` = Port 3 buzzer, `BOTH` = both (optional 30 ms B stagger only if it aids onset legibility — see rule 5). All durations in ms. Per the table note below, the Intensity column is a drive-frequency selector, not an amplitude.

| # | Pattern | Motors | Intensity | Timing spec | Repeats | Total | Class | Queueable | Trigger |
|---|---|---|---|---|---|---|---|---|---|
| **P0** | **READY** | BOTH | 0→65 % | ramp `0→65` over 200, hold `65` for 200 | ×1 | **400** | STATUS | no | Boot complete: ToF init OK, motors OK, Wi-Fi joined or offline confirmed |
| **P1** | **DANGER** | BOTH | 100 % | `(200 on / 150 off) ×5`, then `500` sustained tail | ×4, gap **750** | **2250/cycle · 11 250 total** | **SAFETY** | no | Tier-2b confirmed siren **AND** amplitude trend rising |
| **P2** | **SIREN WARNING** | BOTH | 65 % | `(400 on / 300 off) ×2` | ×1 | **1400** | ALERT | no | Tier-2b confirmed siren, flat or falling trend. Rate-limited 1 per 10 s |
| **P3** | **ATTENTION** | BOTH | 100 % | single `250` pulse | ×1 | **250** | **SAFETY** | no | Tier-2a: 16 consecutive tonal, +12 dB frames with a directional peak sweep of at least 2 bins (~0.5 s) |
| **P4** | **PROXIMITY** | **BOTH** | 2350/3050 Hz audio proxy | `120 on / gap`, `gap = map(mm, 300→1200, 120→900)` — closer = faster | state refreshed on every valid range sample | continuous | HAZARD | no | ToF < 1200 mm on 3 consecutive samples (~150 ms in the isolated runner) |
| **P5** | **BUS ARRIVING** | BOTH | 65 → 82 → 100 % | `(250 on / 250 off) ×3`, ascending | ×1 | **1500** | INFORMATION | no | `BUS_ARRIVED` edge from the relay |
| **P6** | **ROUTE NUMBER** | BOTH | digits **buzz band ~100 Hz**, brackets **alert band ~200 Hz** | preamble `500 @ ~200 Hz` + `600` silence · digits: `LONG=500`, `SHORT=150`, intra-gap `250`, inter-digit gap **800** · terminator `600` silence + `500 @ ~200 Hz` | ×1 | **6400 for "88"** | INFORMATION | **yes** | Claude returned `confidence == "high"` and the 3-vote gate reached consensus |
| **P7** | **WAIT** | BOTH | 2350/3050 Hz audio proxy | `200 on / 600 off / 200 on` | ×1 | **1000** | FEEDBACK | no | Vision request in flight, no result yet |
| **P8** | **UNKNOWN** | BOTH | 100→0 % | single `900` pulse, linear fade-out across its full duration | ×1 | **900** | INFORMATION | **yes** | `confidence == "low"`, **or** the vote failed consensus, **or** the request timed out (>8 s), **or** the route contains a non-digit |
| **P9** | **ACK** | **A only** | 100 % | single `150` pulse, within 20 ms of the press | ×1 | **150** | FEEDBACK | no | Onboard button press, debounced |
| **P10** | **ERROR / OFFLINE** | **BOTH** | 2350/3050 Hz audio proxy | `600 on / 300 off / 150 on / 300 off / 600 on` (long-short-long) | ×1, re-fires every 60 s while degraded | **1950** | STATUS | no | Wi-Fi down >5 s, **or** 5 consecutive ToF I²C failures, **or** 3 consecutive relay failures |

**Reading the table for buzzers:** the **Motors** column (A / B / BOTH) is unchanged in *routing* — A = Port 1 buzzer, B = Port 3 buzzer. The **Intensity** column is now a **drive-frequency** column: read "100 %" as *buzz band (~60–120 Hz)*, "65 %" as a quieter/shorter gate of the same band, and any ramp as a short frequency glide within the buzz band. No pattern depends on a precise amplitude level.

**Directionality is active for camera-derived bus bearing and MOVING-only person avoidance.** **STOP, MOVE OVER, and TURN remain cut** and have no relay trigger or demo step.

The original cut bundled two different claims together. The one that still holds is about **ToF**: a single forward ToF zone cannot choose a safe left/right bypass, so it must never emit a direction. That reasoning does not extend to the **camera**. A bus uses the detector target box's horizontal bearing. While `MOVING`, a selected person box may be sent to the fail-closed Claude endpoint to choose LEFT or RIGHT around the person; uncertainty emits no direction.

P11–P13 are therefore live, not dormant: the phone maps a confirmed bus target bearing to LEFT/RIGHT/AHEAD and a high-confidence person-avoidance decision to LEFT/RIGHT, then posts it to `/api/event`; the board accepts all three direction commands **in both known phases** (`UNKNOWN` refuses). Person production is separately gated to `MOVING`. The user can scan for the bus while STILL, take the first direction before the first step, then keep receiving bus updates while walking. Precedence on the shared channel is owned by `chooseEvent` in `app/src/lib/contract.ts`: while STILL, BUS/NUMBER/UNKNOWN outrank the bearing so arrival and route-88 output still land; while MOVING, a direction wins because the board suppresses the bus-information half there.

What this still does **not** claim: that the wearer can localise the two buzzers spatially (33.941 mm is far below the two-point threshold — the cue is the 2350/3050 Hz frequency contrast, not position), that this is verified navigation, or that the device can confirm the user moved correctly. It is an advisory nudge toward a *dwelling* bus, not turn-by-turn guidance, and low detector confidence must still fire P8 UNKNOWN rather than a guessed direction. The MOVING phase demonstrates obstacle awareness, siren awareness, **and** coarse camera-derived bus bearing.

See `audit/situational-awareness/19-track-a-nav-contract.md`, `20-track-c-nav-firmware.md`, and `23-still-phase-bearing-delivery.md` (the 2026-07-19 both-phases amendment).

### Discriminability analysis

Assessed as felt through a sleeve on the volar wrist, where amplitude is attenuated and fine timing is smeared. Most-confusable first [T3 §Discriminability Analysis].

| Pair | Risk | Separation | Verdict |
|---|---|---|---|
| **P3 ATTENTION vs P9 ACK** | **Highest** — both single short hits | Amplitude (2 motors vs 1, ~2× energy) and duration (250 vs 150 ms, ~1.7×, near the duration JND). **Waveform separation alone is marginal** | **Accepted — resolved by causation, not waveform.** P9 fires only within 20 ms of the user pressing the button. P3 arrives unbidden. Self-disambiguating in every real case |
| **P2 SIREN vs P5 BUS ARRIVING** | **High** — both a few pulses on both channels | Pulse count 2 vs 3; beat 400 vs 250 ms; envelope flat vs ascending | Check semantic clarity in the audio demo; repeat the test from scratch on future vibration hardware |
| **P1 DANGER vs P4 PROXIMITY at close range** | **High in principle** — as an object nears, P4 becomes a fast insistent buzz | Amplitude (both @100 % vs one @100 %); P1 has a 500 ms sustained tail and repeats, P4 never does | **Safe by arbitration, not by waveform.** P1 preempts P4 (SAFETY > HAZARD), so they never overlap, and the mandatory 150 ms clearing gap marks the transition |
| **P1 DANGER vs P10 ERROR** | Medium | Motors (2 vs 1), intensity (100 vs 65 %), rhythm (fast even ×5 vs asymmetric long-short-long), persistence (every 3 s vs every 60 s) | **Safe — four independent margins.** An earlier fast-triplet ERROR was too close to DANGER and was replaced with the asymmetric figure |
| **P6 preamble vs P6 LONG** | Medium — identical duration | Following gap and sequence context; do not infer a tactile pitch distinction from the audio proxy | Retune and re-test on future vibration hardware |
| **P6 LONG (500) vs P6 SHORT (150)** | Low | 3.3× duration ratio, far above the ~20–25 % duration JND. Identical intensity and motor set, so duration is the only varying dimension | **Safe. The cleanest contrast in the vocabulary** — correctly so, because it carries the payload |
| **P7 WAIT vs P4 PROXIMITY** | Low | Both single-motor and repeating, but P4's gap **changes as the user moves their arm** and P7's never does; P7 has 500 ms silent windows, P4 is continuous | **Safe — and the discriminator is embodied.** The user's own motion disambiguates within one arm movement |
| **P8 UNKNOWN vs P0 READY** | Low | Opposite envelopes (900 ms fade-out vs 400 ms ramp-up), 2.25× duration, and P0 fires only at boot | **Safe** |
| **P5's internal 65→82→100 % ramp** | — | Each step is ~15–20 %, right at the vibrotactile Weber fraction | **Do not rely on it.** P5's discriminating feature is **3 pulses**, not the ramp. Stated honestly so nobody builds a claim on it |

**Structural safeguard.** The BOTH-vs-ONE rule means the user's first discrimination is always the easy one — strong vs weak — and it is an amplitude judgement, not a localisation judgement, so it holds at 33.9 mm. Within each half, patterns separate by count and rhythm, the most robust vibrotactile dimensions through fabric. **No pattern requires the user to judge duration and intensity simultaneously.**

**Do not build meaning on apparent motion.** Tactile apparent motion between two actuators is real, but it needs a stimulus onset asynchrony of roughly half the burst duration (~80 ms for a 120 ms burst). Prior drafts specified a 400 ms crossfade, at which the effect does not occur — the user feels two successive buzzes. ERMs additionally have sloppy load-dependent rise and decay, so precise SOA control is poor. **No pattern's semantics may depend on direction** [T3 D18].
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

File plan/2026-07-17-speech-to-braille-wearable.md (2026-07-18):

# Speech-to-Braille Wearable — Implementation Plan

> **For agentic workers:** REQUIRED SUB-SKILL: Use superpowers:subagent-driven-development (recommended) or superpowers:executing-plans to implement this plan task-by-task. Steps use checkbox (`- [ ]`) syntax for tracking.

> **⚠️ AUDIT IS AUTHORITATIVE:** `audit/speech-to-braille-wearable/` is the single source of truth. Where anything in this plan conflicts with an audit file, the audit file wins. The plan records original intent; the audit records what was physically verified and corrected. Always read the audit trail before implementing anything from this plan.

**Goal:** Build a two-way communication wearable for Braille-literate deafblind people — a general-purpose device that turns any spoken utterance from a hearing person into a vibrotactile-Braille "gist" felt on the wrist, and lets the user pick an AI-drafted reply that the app speaks aloud.
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

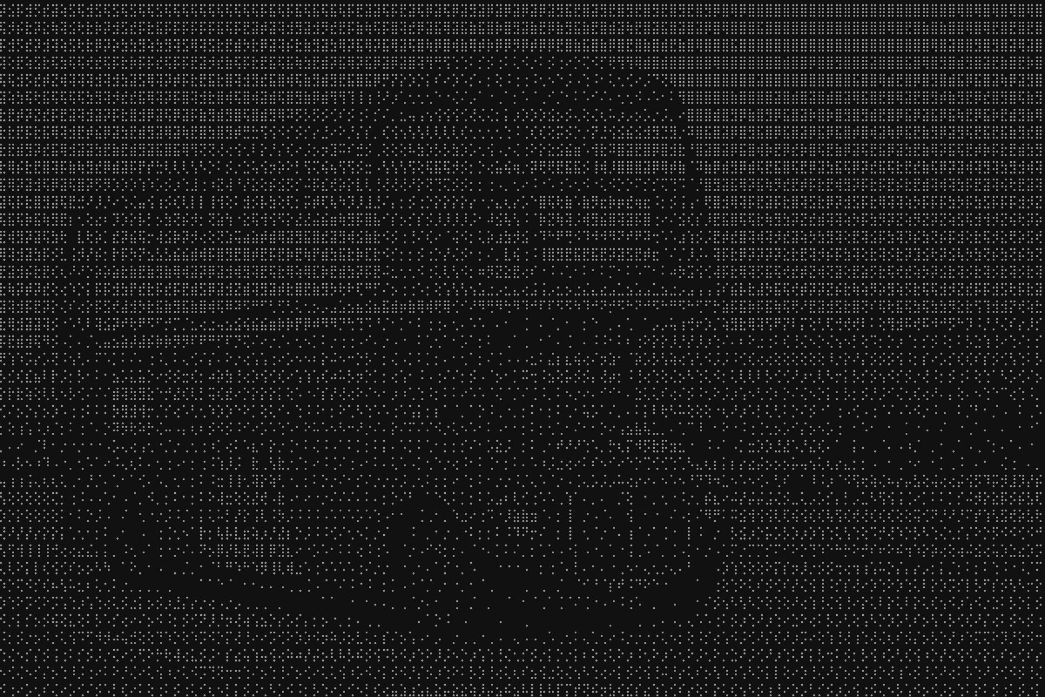
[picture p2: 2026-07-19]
app/public/deck/assets/image-ascii.png

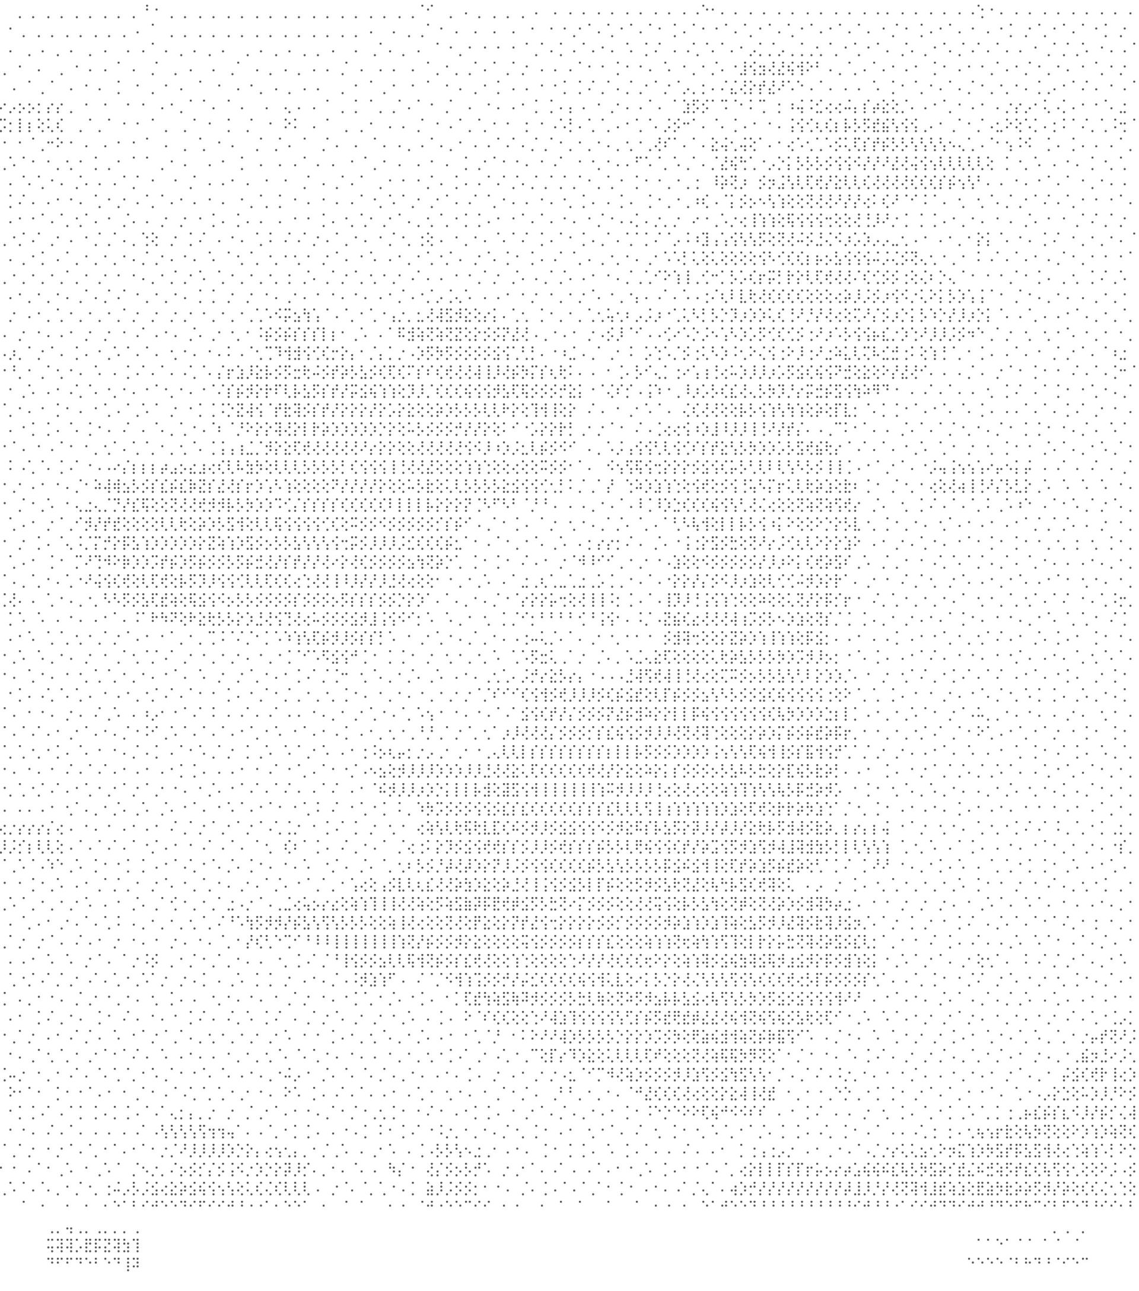
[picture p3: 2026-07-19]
app/public/deck/assets/image-ascii-3.png

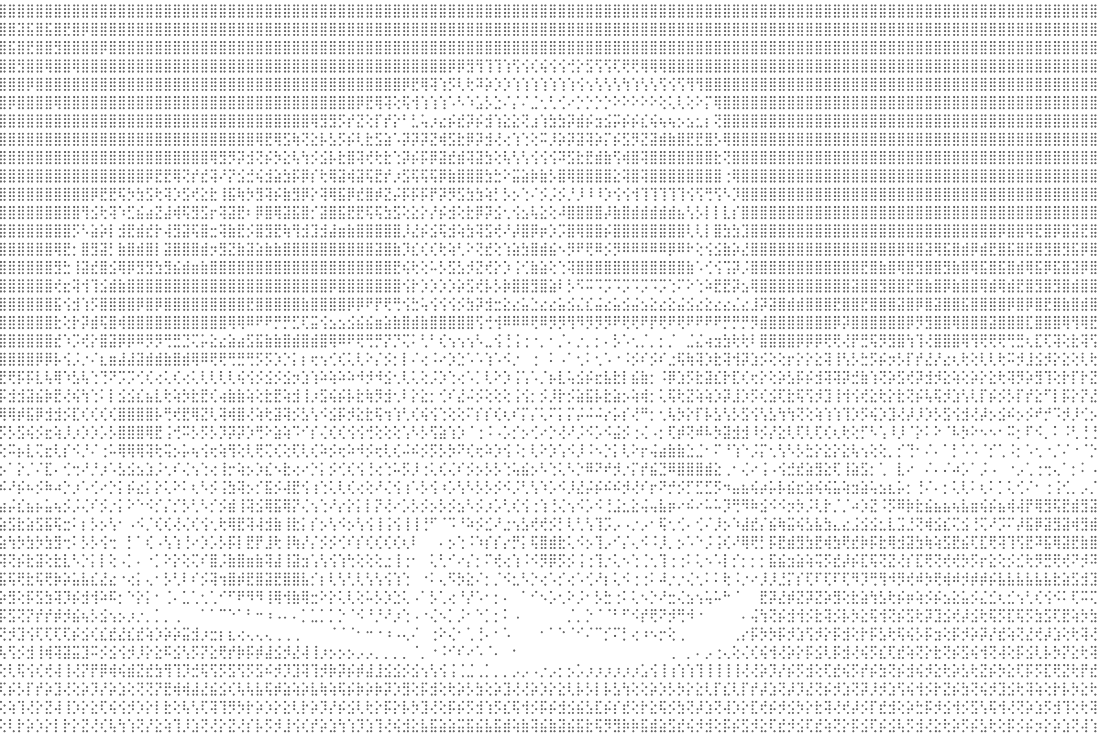
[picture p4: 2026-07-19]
app/public/deck/assets/image-ascii-2.png

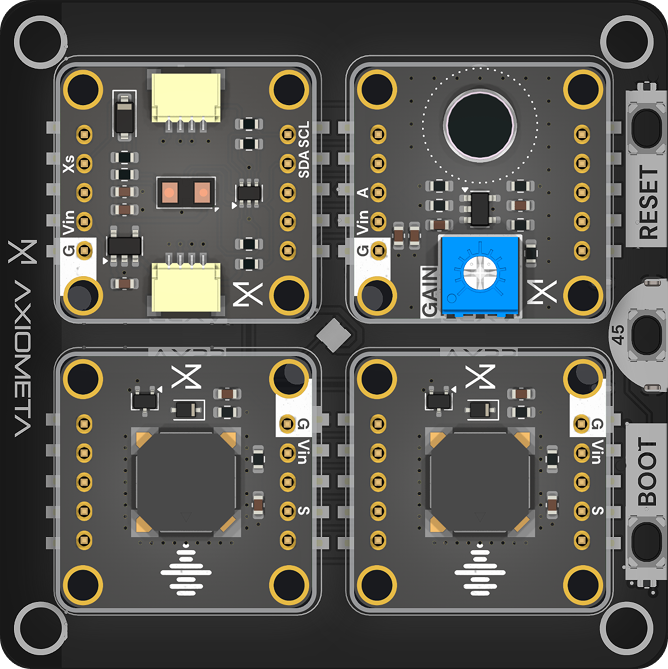
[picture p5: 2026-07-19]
app/public/deck/assets/diagram.png

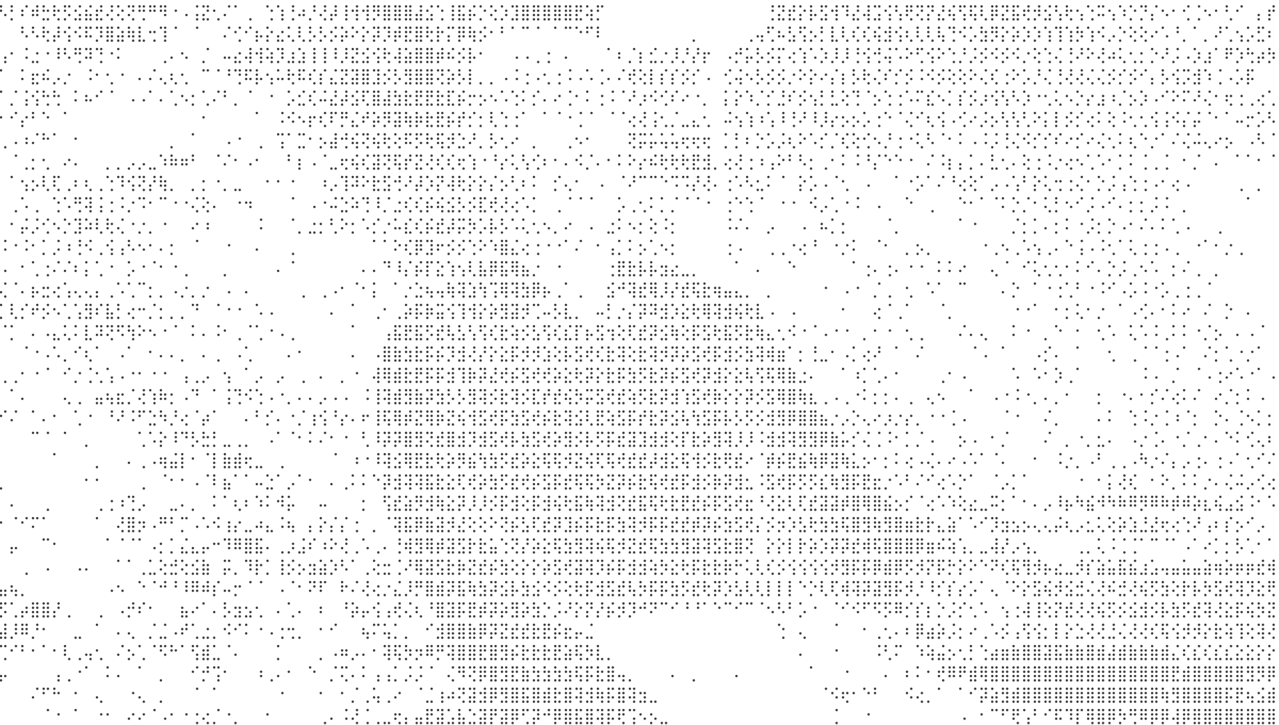
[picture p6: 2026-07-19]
app/public/deck/assets/image-ascii-4.png

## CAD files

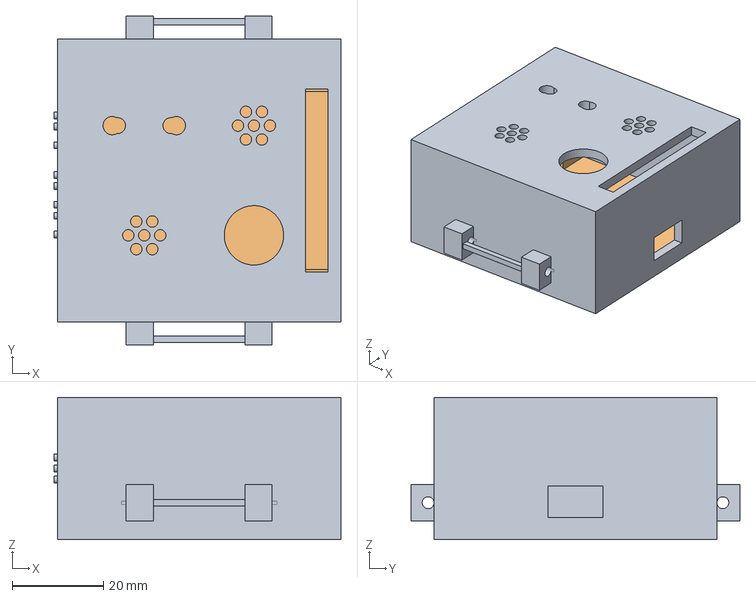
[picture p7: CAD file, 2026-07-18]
cad/enclosure.step
62.7 x 72.0 x 31.2 mm
cage
skin_plate

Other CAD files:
cad/enclosure.stl

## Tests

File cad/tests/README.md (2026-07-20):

# Offline test suite for enclosure.py

`cad/enclosure.py` is a Fusion 360 Python add-in. Fusion has no headless
mode. The script normally runs only inside the Fusion GUI against a live `adsk`
API. This suite runs the script offline. It uses a fake `adsk` package that a real
build123d geometry engine backs. The enclosure builds and gets measured in CI
without Fusion.

## Run

```bash
.venv/bin/python -m pytest cad/tests -q
```

The project venv holds `pytest` and `build123d`. The suite needs no network and no
Fusion. If the venv is absent, the CAD suite cannot run. Report that plainly.

## What the suite checks

`test_enclosure_build.py` is a smoke suite. It guards the current part.

* `test_enclosure_builds`. `run(None)` runs end to end under the fake
  engine and reports no `Failed:` message. A `Failed:` message means a boolean miss
  or an unhandled exception.
* `test_enclosure_two_named_bodies`. The build yields exactly two bodies,
  `cage` and `skin_plate`.

## How it works

* `fake_adsk/` implements the `adsk.core` and `adsk.fusion` surface that the script
  touches. `conftest.py` aliases it as `adsk` in `sys.modules` before it imports the
  script. It imports the script by path, because `cad/` has no `__init__.py`. It
  re-imports the script fresh for each test, so the module globals never leak. The
  `run_build(...)` helper resets the fake world, runs the add-in, and returns a
  small result object. The object exposes `failed`, `final_message`,
  `world.body_names()`, and per-point `is_solid()` probes.
* The engine runs sketches, extrudes, and booleans as build123d solids. Units follow
  the script. The fake API speaks centimetres. The script divides millimetres by 10.
  The solids build in millimetres.
* The booleans copy Fusion semantics. `NEWBODY` makes a body. `JOIN` fuses into any
  touching body, and raises if the bodies are disjoint. `CUT` subtracts, and raises
  `RuntimeError("3 : No target body found to cut or intersect!")` when the tool
  intersects no existing body. Live Fusion raises the same error.
* The orientation is a parametrized convention. The sketch frame on an offset `yZ`
  plane is configurable. The options are `identity`, `mirrored`, and `rotated`. A
  script that hard-codes the axis mapping mis-places geometry under `mirrored`, and
  the suite catches it.

The harness came from the earlier enclosure in this project. It carries more
capability than the current smoke suite uses. It can run point-in-solid material
probes, orientation-invariance checks, and dimension-registry invariants. A
contributor who tightens the enclosure fit can add those deeper assertions
here through the same `run_build` API.

## What it cannot catch

* The real, undocumented Fusion construction-plane frame conventions. The engine
  models a family of conventions to prove invariance. The true in-Fusion mapping is
  ground truth only inside Fusion.
* Timeline and parametric-associativity quirks, feature-ordering rollback, and the
  way Fusion resolves faces and edges for chamfers. Chamfers here are recorded, not
  applied. Only the edge-selection code runs.
* UI behaviour, document and unit setup, and any real messageBox rendering.

The in-Fusion run stays ground truth. This suite is a fast regression net for the
geometry-logic bug classes above. It is not a substitute for a run inside Fusion.

## Pointers

* `f360mock`, a mock Fusion API. https://github.com/bommerio/f360mock
* AU class, Testing Strategies for Python Fusion 360 Add-Ins (2017). https://www.autodesk.com/autodesk-university/class/Testing-Strategies-Python-Fusion-360-Add-Ins-2017
* Forum thread on unit tests and CI for Fusion add-ins. https://forums.autodesk.com/t5/fusion-api-and-scripts-forum/unit-tests-for-fusion-360-add-ins-and-running-them-on-the-ci-cd/td-p/11600462

## Layout

```
cad/tests/
  fake_adsk/          # importable as `adsk` via conftest sys.modules aliasing
    __init__.py       # exposes core, fusion, cam; reset() helper
    core.py           # ValueInput, Point3D, Matrix3D, ObjectCollection, Line3D,
                      #   Application and UserInterface plus harness state
    fusion.py         # Design, Component, Sketch, features, and the build123d engine
    cam.py            # stub, imported but unused
  conftest.py         # sys.modules aliasing, fresh script import, run_build
  test_enclosure_build.py
  README.md
```

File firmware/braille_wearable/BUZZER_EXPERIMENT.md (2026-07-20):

# Two-Buzzer Audio Proxy

Tacta delivers situational awareness through touch. Two vibration channels are how the wearable speaks to the wearer. The first-hour tactile test failed. Both AX22-0018 modules were audible but produced virtually no felt movement. They remain in the hack demo only as audible proxies for two future vibration-motor channels. This setup validates software routing and pattern timing, not tactile efficacy or accessibility.

## Configure The Board

1. Disconnect USB power before fitting or moving any module.
2. Fit one AX22-0018 passive buzzer in **P1**. Treat this as **LEFT**.
3. Fit the AX22-0050 tactile LED button in **P2**. It is the start/stop control.
4. Fit the second AX22-0018 passive buzzer in **P3**. Treat this as **RIGHT**.
5. Leave **P4 empty** for this test.
6. The 2x5 sockets are not keyed. On every module, align the `G` / GND pin-1 corner with the socket corner marked `G`. Check this twice; do not power a module inserted 180 degrees around.
7. Reconnect the board by USB-C. The buzzers no longer need to be strapped to the wrist.

The verified signal mapping is P1 buzzer IO1 to GPIO3, P2 button IO1 to GPIO6, P2 LED IO2 to GPIO5, and P3 buzzer IO1 to GPIO16. The button is active-low and the LED is active-high. Disconnect power again before correcting any placement. Keep the buzzers on the wrist or bench and never near an ear.

P2 is used only by this isolated experiment. The full prototype later needs P2 for the ToF sensor, so remove the button before returning to the main hardware plan.

## Build, Upload, And Monitor

Run these commands from the repository root.

```bash
cd firmware/braille_wearable
../../.venv/bin/pio run -e buzzer_experiment
../../.venv/bin/pio run -e buzzer_experiment -t upload
../../.venv/bin/pio device monitor -e buzzer_experiment
```

The serial monitor runs at 115200 baud. Press `h` to print the controls. If PlatformIO finds more than one upload port, add `--upload-port /dev/cu.usbmodem...` to the upload command and `-p /dev/cu.usbmodem...` to the monitor command.

## Start And Stop

The firmware boots disarmed with both buzzers silent and the P2 LED off.

1. Press the P2 LED button once. The LED turns on, which means buzzer output is armed.
2. In Serial, enter `v`, `n`, or `s` to choose the channel check, navigation simulation, or situational simulation.
3. Press the P2 button again at any time to stop immediately. Both buzzers and the LED turn off and the current session is discarded.

The LED also turns off automatically when a check or 12-trial session finishes. Entering `x` in Serial is the software stop equivalent. Serial remains part of the demo because the operator uses it to select a pattern and record guesses.

## Interpretation Boundary

P1 / LEFT always uses 2350 Hz. P3 / RIGHT always uses 3050 Hz. The exact 700 Hz separation is preserved while both tones sit closer to the MLT-8530's 2.7 kHz resonance. Simultaneous patterns play both proxy tones; alternating patterns alternate them.

These mappings simulate the two channels that future ERM or LRA vibration motors would provide. Hearing or scoring these patterns does not show that real motors will be felt, spatially localized, or distinguishable. That requires retuning and testing with actual vibration hardware and representative users.

## Run The Test

### 1. Audio Channel Check

Press the P2 button to arm, then enter `v`. The firmware plays P1 / LEFT at 2350 Hz and then P3 / RIGHT at 3050 Hz. This confirms audible output and channel routing only.

### 2. Navigation Simulation

Press the P2 button to arm, then enter `n` for 12 balanced, shuffled audio trials.

- For a perceived LEFT, the operator enters `l`.
- For a perceived RIGHT, the operator enters `r`.
- To replay without revealing the answer, the operator enters `p`.

LEFT is P1 at 2350 Hz. RIGHT is P3 at 3050 Hz. The score checks whether the audio labels and software path are clear; it is not a tactile navigation result.

### 3. Situational Simulation

Press the P2 button to arm, then enter `s` for 12 balanced, shuffled audio trials.

- For a perceived EVENT or arrival, the operator enters `e`.
- For a perceived WAIT, the operator enters `w`.
- To replay without revealing the answer, the operator enters `p`.

EVENT is three simultaneous two-tone pulses. WAIT alternates the 2350 Hz and 3050 Hz channels twice. The score checks semantic and timing clarity only.

## Record The Result

```text
Date / operator:
LEFT 2350 Hz audible and routed correctly:
RIGHT 3050 Hz audible and routed correctly:
Navigation simulation score:  /12
Situational simulation score: /12
Replays used:
Routing or timing problems:
```

The binding tactile result is already recorded in `audit/situational-awareness/05-buzzer-bench-test.md`. These buzzer modules are not viable haptic actuators.

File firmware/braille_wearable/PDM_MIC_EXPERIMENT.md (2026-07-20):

# PDM Microphone Experiment

Tacta fuses cameras, microphones, and depth sensors into situational awareness
delivered by touch. The microphone is the local sound sense. This isolated runner
proves that the AX22-0044/T3902 in P4 delivers healthy 16-bit PCM before FFT or
siren-classification code is connected.

## P4 Mapping

The module silk reads `G / 3V3 / SL / DT / CLK`.

| Module signal | Genesis Mini P4 signal | ESP32-S3 GPIO |
|---|---|---|
| CLK | IO2 | GPIO18 |
| DT | IO1 | GPIO17 |
| SL | IO0 | GPIO1 |

The runner drives `SL` high. The T3902 datasheet calls select-high its DATA2
or left lane, while ESP-IDF names the pulled-high receive mask
`I2S_PDM_SLOT_RIGHT`. The runner uses the ESP-IDF name required by the installed
driver. Capture must remain on `I2S_NUM_0`, where ESP32-S3 provides PDM-to-PCM
conversion.

## Build, Upload, And Monitor

```bash
cd firmware/braille_wearable
$HOME/.platformio/penv/bin/pio test -e native
$HOME/.platformio/penv/bin/pio run -e pdm_mic_experiment
$HOME/.platformio/penv/bin/pio run -e pdm_mic_experiment -t upload --upload-port /dev/cu.usbmodem1101
$HOME/.platformio/penv/bin/pio device monitor -e pdm_mic_experiment --port /dev/cu.usbmodem1101 --baud 115200
```

The runner prints one aggregate line per second.

```text
PDM frames=32 partial=0 errors=0 mean=... sigma=... peak_sigma=... min=... max=... clipping=0 health=HEALTHY
```

## Physical Gate

1. Leave the board still and record several quiet-room lines.
2. Speak near the microphone, then clap once nearby.
3. Confirm `sigma`, `peak_sigma`, and the extrema react to sound.
4. Confirm frames continue near 32 per second with no persistent partial reads,
   read errors, or clipping.

`SILENT_OR_WRONG_SLOT` means every captured frame is effectively constant.
Verify that SL/GPIO1 is driven high and the slot mask remains `I2S_PDM_SLOT_RIGHT`
before changing the pin map. `RAW_PDM_OR_EXCESSIVE_NOISE` means the signal is
too variable for the bring-up threshold; first verify that capture is still on
`I2S_NUM_0`.

Passing this gate proves PCM capture and sound response only. It does not prove
that sirens can be distinguished from other environmental sounds.

The 2026-07-18 physical run passed. Quiet sigma was commonly 20-60 LSB; a
nearby repeatable system sound raised one-second sigma above 100 LSB and peak
frame sigma above 350 LSB, while capture held 32 frames per second with no read
errors or clipping. See `audit/situational-awareness/08-pdm-microphone-bench-test.md`.

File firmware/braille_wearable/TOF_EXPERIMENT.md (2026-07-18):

# ToF Proximity Experiment

This isolated firmware validates the AX22-0015 VL53L0CX and a device-local
proximity response. It does not require Wi-Fi, the web app, or Modal.

## Module Placement

Disconnect USB-C before moving modules. The four sockets are not keyed, so
align each module's `G` / `GND` corner with the socket's ground corner.

| Port | Module | Signals |
| --- | --- | --- |
| P1 | AX22-0018 passive buzzer | IO1 / GPIO3, 2350 Hz LEFT proxy |
| P2 | AX22-0015 VL53L0CX | SDA / GPIO10, SCL / GPIO11, XSHUT / GPIO6 |
| P3 | AX22-0018 passive buzzer | IO1 / GPIO16, 3050 Hz RIGHT proxy |
| P4 | Empty | Reserved for the PDM microphone |

Remove the AX22-0050 LED button from P2 before fitting the ToF module.

## Build And Upload

```bash
cd firmware/braille_wearable
../../.venv/bin/pio test -e native
../../.venv/bin/pio run -e tof_experiment
../../.venv/bin/pio run -e tof_experiment -t upload
../../.venv/bin/pio device monitor -e tof_experiment
```

The monitor uses 115200 baud. The board should print `READY component=tof`
followed by `TOF` records. `status=0 valid=1` is a usable sample.

## Controls

- `r`: toggle the local proximity audio proxy.
- `x`: immediately silence and disable the proxy.
- `1`..`6`: capture five seconds at an expected 300, 600, 1200, 2000,
  3000, or 4000 mm respectively.
- `h`: print controls.

Raw range diagnostics continue regardless of reflex state. During a five-second
benchmark window, per-sample lines are suppressed and replaced by one
`BENCH result` summary. The proxy is off at boot so a sensor or firmware reset
cannot start an unexpected tone.

## Controlled Range Gate

ST specifies an absolute maximum range of 2 m for the VL53L0X. Under a fully
covered 25-degree field of view, its published minimum detection distances are
1.2 m for a white indoor target, 0.7 m for a gray indoor target, 0.6 m for a
white outdoor target, and 0.4 m for a gray outdoor target. The Axiometa catalog
claims 4 m, so 3 m and 4 m are measured as exploratory points rather than
assumed capabilities. Source: [ST VL53L0X datasheet, Rev 6](https://www.st.com/resource/en/datasheet/vl53l0x.pdf),
sections 6.1 and 6.2.

1. Use a tape measure from the sensor face to a flat wall. Record wall colour,
   surface, lighting, and whether the sensor is hand-held or braced.
2. Keep the sensor perpendicular and motionless. A wall is preferred because
   the 25-degree field of view spans about 1.8 m at a 4 m distance.
3. At 300, 600, 1200, 2000, 3000, and 4000 mm, enter `1`, `2`, `3`, `4`, `5`,
   or `6`. Do not move anything until the `BENCH result` line appears.
4. Record sample count, valid percentage, minimum, mean, maximum, mean absolute
   error, and failure-status counts. Treat at least 94% valid returns as the
   detection-rate gate; do not infer a pass from isolated valid samples.
5. Repeat the useful range with a dark target and, separately, in outdoor
   ambient light before selecting a product threshold.
6. Enter `r`. Move the target closer and confirm the P1 2350 Hz pulse gap gets
   shorter.
7. Enter `x` during a pulse and confirm it stops immediately.
8. Unplug the network or run without credentials. The response must be
   unchanged because this path is entirely local.

The audible response is a simulation of future motor channel A. It validates
sensor-to-output behavior, not tactile perception.

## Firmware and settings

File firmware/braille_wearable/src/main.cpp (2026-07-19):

#include <Arduino.h>
#include <math.h>
#include <string.h>

#include "audio.h"
#include "haptic.h"
#include "haptic_pure.h"
#include "navigation_pure.h"
#include "net.h"
#include "output_telemetry_pure.h"
#include "patterns.h"
#include "siren_runtime_pure.h"
#include "tof.h"

namespace {

constexpr uint16_t PROXIMITY_PULSE_ON_MS = 120;
constexpr uint32_t READY_DELAY_MS = 1100;

ActivityControlState activityControl;
RelaySequenceState relaySequence;
UserActivity currentActivity = UserActivity::MOVING;
PatternPlayer cloudPlayer;
OutputTelemetrySource cloudPlayerSource = OutputTelemetrySource::NONE;
const OutputPattern* pendingCloudPattern = nullptr;
OutputTelemetrySource pendingCloudPlayerSource = OutputTelemetrySource::NONE;
bool cloudClearing = false;
uint32_t cloudClearingStartedMs = 0;
PatternPlayer sirenPlayer;
OutputEnableLatch outputLatch;
SirenDecision activeSirenOutput = SirenDecision::NONE;
SirenDecision detectedSiren = SirenDecision::NONE;
const OutputPattern* pendingSirenPattern = nullptr;
bool sirenClearing = false;
uint32_t sirenClearingStartedMs = 0;
bool proximityActive = false;
bool proximityOutputAllowed = false;
bool proximityToneOn = false;
bool proximityClearing = false;
uint16_t proximityGapMs = PROXIMITY_SLOW_GAP_MS;
uint32_t proximityClearingStartedMs = 0;
uint32_t nextProximityTransitionMs = 0;
bool readyPending = true;
uint32_t readyEligibleAtMs = 0;
RelayTelemetry relayTelemetry;
uint32_t lastTelemetryPublishMs = 0;
bool hasOutputTelemetry = false;
HapticDrive lastOutputTelemetryDrive{0, 0};
OutputSemanticSnapshot lastOutputTelemetrySnapshot{
    OutputTelemetryState::IDLE,
    OutputTelemetrySource::NONE,
    "NONE",
    UserActivity::MOVING,
    OutputTelemetryReason::NO_OUTPUT,
    -1,
    DEFAULT_OUTPUT_MODE,
};
uint32_t lastOutputTelemetryMs = 0;

void startSirenOutput(SirenDecision decision, uint32_t nowMs);

bool sirenOutputActive() {
    return activeSirenOutput != SirenDecision::NONE;
}

bool proximityCanRender() {
    return shouldRenderProximity(currentActivity, proximityActive,
                                 proximityOutputAllowed);
}

bool cloudAvoidanceDirectionActive() {
    if (cloudClearing) return true;
    if (cloudPlayerSource != OutputTelemetrySource::RELAY ||
        !patternOutput(cloudPlayer).active) {
        return false;
    }
    return cloudPlayer.pattern == &LEFT_PATTERN ||
           cloudPlayer.pattern == &RIGHT_PATTERN;
}

bool proximityOwnsOutput() {
    return proximityCanRender() && !cloudAvoidanceDirectionActive();
}

void clearPendingCloudPattern() {
    pendingCloudPattern = nullptr;
    pendingCloudPlayerSource = OutputTelemetrySource::NONE;
    cloudClearing = false;
}

const OutputPattern& patternForSirenDecision(SirenDecision decision) {
    switch (decision) {
        case SirenDecision::ATTENTION: return ATTENTION_PATTERN;
        case SirenDecision::SIREN_WARNING: return SIREN_WARNING_PATTERN;
        case SirenDecision::DANGER: return DANGER_PATTERN;
        case SirenDecision::NONE: return ATTENTION_PATTERN;
    }
    return ATTENTION_PATTERN;
}

void stopCloudPattern() {
    const bool wasAvoidanceDirection = cloudAvoidanceDirectionActive();
    clearPendingCloudPattern();
    stopPattern(cloudPlayer);
    if (wasAvoidanceDirection && proximityCanRender() && !sirenOutputActive()) {
        proximityToneOn = false;
        proximityClearing = true;
        proximityClearingStartedMs = millis();
        hapticStop();
    } else if (!proximityCanRender() && !sirenOutputActive()) {
        hapticStop();
    }
}

void refreshEffectiveActivity(uint32_t nowMs, const char* source) {
    const UserActivity nextActivity = effectiveActivity(activityControl, nowMs);
    if (currentActivity == nextActivity) {
        return;
    }

    const UserActivity previousActivity = currentActivity;
    currentActivity = nextActivity;
    clearPendingCloudPattern();
    stopPattern(cloudPlayer);
    if (activityTransitionClearsProximity(previousActivity, currentActivity)) {
        proximityToneOn = false;
        proximityClearing = false;
        if (!sirenOutputActive()) {
            hapticStop();
        }
        Serial.printf("PROXIMITY output=cleared reason=activity_%s\n",
                      userActivityName(currentActivity));
    } else if (proximityCanRender() && !sirenOutputActive()) {
        stopPattern(cloudPlayer);
        proximityToneOn = false;
        proximityClearing = true;
        proximityClearingStartedMs = nowMs;
        hapticStop();
    }
    Serial.printf("ACTIVITY changed=%s previous=%s source=%s\n",
                  userActivityName(currentActivity),
                  userActivityName(previousActivity), source);
}

void setServiceActivityMode(UserActivity activity) {
    if (activity == UserActivity::UNKNOWN) {
        return;
    }
    setServiceActivity(activityControl, activity);
    refreshEffectiveActivity(millis(), "service_serial");
    Serial.printf("ACTIVITY service_override=%s\n", userActivityName(activity));
}

void clearServiceActivityMode() {
    clearServiceActivity(activityControl);
    refreshEffectiveActivity(millis(), "relay_control");
    Serial.println(F("ACTIVITY service_override=cleared source=relay"));
}

void submitCloudCommand(CloudCommand command, const char* name,
                        OutputTelemetrySource source) {
    switch (evaluateCommandGate(outputLatch.enabled, currentActivity, command,
                                proximityCanRender(), sirenOutputActive())) {
        case CommandGate::OUTPUT_STOPPED:
            Serial.printf("COMMAND dropped=%s reason=output_stopped\n", name);
            return;
        case CommandGate::ACTIVITY_GATE:
            Serial.printf("COMMAND dropped=%s activity=%s reason=activity_gate\n",
                          name, userActivityName(currentActivity));
            return;
        case CommandGate::LOCAL_PROXIMITY:
            Serial.printf("COMMAND dropped=%s activity=%s reason=local_proximity\n",
                          name, userActivityName(currentActivity));
            return;
        case CommandGate::LOCAL_SIREN:
            Serial.printf("COMMAND dropped=%s activity=%s reason=local_siren\n",
                          name, userActivityName(currentActivity));
            return;
        case CommandGate::ALLOW:
            break;
    }
    const OutputPattern* pattern = cloudPattern(command);
    if (pattern == nullptr) {
        Serial.printf("COMMAND unsupported=%s\n", name);
        return;
    }
    const uint32_t nowMs = millis();
    if (proximityCanRender() && mayInterruptProximity(command)) {
        stopPattern(cloudPlayer);
        proximityToneOn = false;
        proximityClearing = false;
        hapticStop();
        pendingCloudPattern = pattern;
        pendingCloudPlayerSource = source;
        cloudClearing = true;
        cloudClearingStartedMs = nowMs;
        Serial.printf("COMMAND transition=%s from=PROXIMITY clearing_ms=%u\n",
                      name, HAPTIC_CLEARING_GAP_MS);
    } else {
        clearPendingCloudPattern();
        startPattern(cloudPlayer, *pattern, nowMs);
        cloudPlayerSource = source;
    }
    Serial.printf("COMMAND accepted=%s activity=%s\n", name,
                  userActivityName(currentActivity));
}

void submitServiceDirection(ServiceDirection direction, const char* name) {
    if (!outputLatch.enabled) {
        Serial.printf("CHANNEL_SIMULATION dropped=%s reason=output_stopped\n", name);
        return;
    }
    if (currentActivity != UserActivity::MOVING) {
        Serial.printf("CHANNEL_SIMULATION dropped=%s activity=%s reason=movement_only\n",
                      name, userActivityName(currentActivity));
        return;
    }
    if (proximityCanRender() || sirenOutputActive()) {
        Serial.printf("CHANNEL_SIMULATION dropped=%s reason=local_priority\n", name);
        return;
    }
    const OutputPattern* pattern = serviceDirectionPattern(direction);
    if (pattern != nullptr) {
        startPattern(cloudPlayer, *pattern, millis());
        cloudPlayerSource = OutputTelemetrySource::SERVICE;
        Serial.printf("CHANNEL_SIMULATION accepted=%s claim=concept_only\n", name);
    }
}

void printHelp() {
    Serial.println();
    Serial.println(F("=== Integrated board firmware: local sensing + relay gate ==="));
    Serial.println(F("n/s  service override MOVING or STILL"));
    Serial.println(F("c  clear service override and return activity control to relay"));
    Serial.println(F("l/r/a  conceptual channel simulation only; no sensed direction"));
    Serial.println(F("b/w  BUS or WAIT relay-scenario input"));
    Serial.println(F("8/u/e  route 88, UNKNOWN, or ERROR relay-scenario input"));
    Serial.println(F("x  emergency stop all output; sensing continues"));
    Serial.println(F("o  resume board output after an emergency stop"));
    Serial.println(F("q/v  NIGHT hardware mute or AUDIBLE output mode"));
    Serial.println(F("h  print this help"));
    Serial.println(F("ToF samples in both states but outputs only while MOVING."));
    Serial.println(F("Siren sensing and output run locally in both states."));
    Serial.println();
}

void handleSerial(char command) {
    if (command >= 'A' && command <= 'Z') {
        command = static_cast<char>(command - 'A' + 'a');
    }
    switch (command) {
        case 'n': setServiceActivityMode(UserActivity::MOVING); break;
        case 's': setServiceActivityMode(UserActivity::STILL); break;
        case 'c': clearServiceActivityMode(); break;
        case 'l': submitServiceDirection(ServiceDirection::LEFT, "LEFT"); break;
        case 'r': submitServiceDirection(ServiceDirection::RIGHT, "RIGHT"); break;
        case 'a': submitServiceDirection(ServiceDirection::AHEAD, "AHEAD"); break;
        case 'b':
            submitCloudCommand(CloudCommand::BUS, "BUS",
                               OutputTelemetrySource::SERVICE);
            break;
        case 'w':
            submitCloudCommand(CloudCommand::WAIT, "WAIT",
                               OutputTelemetrySource::SERVICE);
            break;
        case '8':
            submitCloudCommand(CloudCommand::NUMBER, "NUMBER_88",
                               OutputTelemetrySource::SERVICE);
            break;
        case 'u':
            submitCloudCommand(CloudCommand::UNKNOWN, "UNKNOWN",
                               OutputTelemetrySource::SERVICE);
            break;
        case 'e':
            submitCloudCommand(CloudCommand::ERROR, "ERROR",
                               OutputTelemetrySource::SERVICE);
            break;
        case 'x':
            clearPendingCloudPattern();
            stopPattern(cloudPlayer);
            stopPattern(sirenPlayer);
            activeSirenOutput = SirenDecision::NONE;
            pendingSirenPattern = nullptr;
            sirenClearing = false;
            stopAllOutput(outputLatch);
            proximityToneOn = false;
            hapticStop();
            Serial.println(F("OUTPUT stopped=all sensing=active"));
            break;
        case 'o':
            resumeOutput(outputLatch);
            if (proximityCanRender()) {
                proximityToneOn = false;
                proximityClearing = true;
                proximityClearingStartedMs = millis();
            }
            if (detectedSiren != SirenDecision::NONE) {
                startSirenOutput(detectedSiren, millis());
            }
            Serial.println(F("OUTPUT resumed=all"));
            break;
        case 'q':
            hapticSetOutputMode(OutputMode::NIGHT);
            Serial.println(F("NIGHT_MODE active=1 hardware=muted telemetry=active"));
            break;
        case 'v':
            hapticSetOutputMode(OutputMode::AUDIBLE);
            Serial.println(F("NIGHT_MODE active=0 hardware=enabled telemetry=active"));
            break;
        case 'h': printHelp(); break;
        case '\r':
        case '\n': break;
        default: Serial.println(F("Unknown command. Enter h for controls.")); break;
    }
}

void startSirenOutput(SirenDecision decision, uint32_t nowMs) {
    if (!outputLatch.enabled) {
        Serial.printf("SIREN_OUTPUT dropped=%s reason=output_stopped\n",
                      sirenDecisionName(decision));
        return;
    }
    if (!canStartSirenOutput(decision, activeSirenOutput, proximityCanRender())) {
        Serial.printf("SIREN_OUTPUT dropped=%s active=%s proximity=%u reason=priority\n",
                      sirenDecisionName(decision),
                      sirenDecisionName(activeSirenOutput),
                      proximityCanRender() ? 1 : 0);
        return;
    }

    const bool preempting = patternOutput(cloudPlayer).active ||
                            cloudClearing ||
                            patternOutput(sirenPlayer).active ||
                            proximityCanRender();
    stopPattern(cloudPlayer);
    clearPendingCloudPattern();
    stopPattern(sirenPlayer);
    proximityToneOn = false;
    hapticStop();

    activeSirenOutput = decision;
    pendingSirenPattern = &patternForSirenDecision(decision);
    sirenClearing = preempting;
    sirenClearingStartedMs = nowMs;
    if (!sirenClearing) {
        startPattern(sirenPlayer, *pendingSirenPattern, nowMs);
        pendingSirenPattern = nullptr;
    }
    Serial.printf("SIREN_OUTPUT accepted=%s clearing_ms=%u\n",
                  sirenDecisionName(decision),
                  sirenClearing ? HAPTIC_CLEARING_GAP_MS : 0);
}

void serviceAudio(uint32_t nowMs) {
    SirenDecision currentDecision = SirenDecision::NONE;
    if (audioPollCurrentDecision(currentDecision)) {
        detectedSiren = currentDecision;
    }

    SirenDecision decision = SirenDecision::NONE;
    while (audioPollDecision(decision)) {
        startSirenOutput(decision, nowMs);
    }

    AudioTelemetry telemetry{};
    if (audioPollTelemetry(telemetry)) {
        constexpr float BAND_BIN_COUNT =
            SIREN_ENERGY_LAST_BIN - SIREN_ENERGY_FIRST_BIN + 1;
        relayTelemetry.bandRms = sqrtf(telemetry.features.bandEnergy / BAND_BIN_COUNT);
        relayTelemetry.peakHz = static_cast<uint16_t>(
            telemetry.features.peakBin * SIREN_BIN_HZ);
        relayTelemetry.trendRising = telemetry.decision == SirenDecision::DANGER;
        Serial.printf(
            "AUDIO frames=%lu partial=%lu errors=%lu dropped=%lu sigma=%.1f "
            "band=%.3e floor=%.3e peak_bin=%u peak_ratio=%.3f health=%s decision=%s\n",
            static_cast<unsigned long>(telemetry.fullFrames),
            static_cast<unsigned long>(telemetry.partialReads),
            static_cast<unsigned long>(telemetry.readErrors),
            static_cast<unsigned long>(telemetry.droppedDecisions),
            telemetry.frame.standardDeviation,
            telemetry.features.bandEnergy,
            telemetry.features.noiseFloorEstimate,
            telemetry.features.peakBin,
            telemetry.features.peakEnergyRatio,
            audioFrameHealthName(telemetry.health),
            sirenDecisionName(telemetry.decision));
    }
}

void serviceReady(uint32_t nowMs) {
    if (!readyPending || !outputLatch.enabled || proximityCanRender() ||
        sirenOutputActive() || patternOutput(cloudPlayer).active ||
        static_cast<int32_t>(nowMs - readyEligibleAtMs) < 0) {
        return;
    }
    readyPending = false;
    startPattern(cloudPlayer, READY_PATTERN, nowMs);
    cloudPlayerSource = OutputTelemetrySource::SYSTEM;
    Serial.printf("READY activity=%s transport=%s tof=local mic=local\n",
                  userActivityName(currentActivity),
                  relayNetworkConfigured() ? "relay" : "offline_service");
}

void serviceSerial() {
    while (Serial.available() > 0) {
        handleSerial(static_cast<char>(Serial.read()));
    }
}

void applyTofUpdate(const TofUpdate& update, uint32_t nowMs) {
    if (!update.updated) {
        return;
    }

    const bool wasActive = proximityActive;
    const bool wasRendering = proximityCanRender();
    proximityActive = update.proximity.active;
    proximityOutputAllowed = update.proximity.outputAllowed;
    proximityGapMs = update.proximity.pulseGapMs;
    if (update.status == 0 && update.distanceMm > 0) {
        relayTelemetry.tofMm = update.distanceMm;
    }

    if (update.proximity.entered) {
        if (proximityCanRender() && !cloudAvoidanceDirectionActive()) {
            stopPattern(cloudPlayer);
            if (activeSirenOutput == SirenDecision::SIREN_WARNING) {
                stopPattern(sirenPlayer);
                activeSirenOutput = SirenDecision::NONE;
                pendingSirenPattern = nullptr;
                sirenClearing = false;
            }
            proximityToneOn = false;
            if (!sirenOutputActive()) {
                proximityClearing = true;
                proximityClearingStartedMs = nowMs;
                hapticStop();
            }
        }
        Serial.printf("PROXIMITY entered mm=%u activity=%s output=%s\n",
                      update.distanceMm,
                      userActivityName(currentActivity),
                      proximityCanRender() ? "enabled" : "suppressed");
    }
    if (update.proximity.exited) {
        proximityToneOn = false;
        proximityClearing = false;
        if (wasRendering && !sirenOutputActive()) {
            hapticStop();
        }
        Serial.println(F("PROXIMITY exited"));
    }
    if (wasActive && !proximityOutputAllowed &&
        allowsProximityOutput(currentActivity)) {
        proximityToneOn = false;
        if (!sirenOutputActive()) {
            hapticStop();
        }
    }
    if (update.timedOut) {
        Serial.println(F("TOF invalid=range_timeout output=revoked"));
    }
}

void serviceRelay(uint32_t nowMs) {
    RelayUpdate update{};
    while (relayPollUpdate(update)) {
        if (update.resetCommandBaseline) {
            resetRelayControlAfterOutage(relaySequence, activityControl);
            refreshEffectiveActivity(nowMs, "long_outage");
            Serial.println(F("RELAY command=baseline_reset activity=invalidated reason=long_outage"));
        }
        if (update.hasActivity) {
            if (update.activity == UserActivity::UNKNOWN) {
                invalidateCloudActivity(activityControl);
                Serial.printf("RELAY activity=invalidated override=%u\n",
                              activityControl.serviceOverride ? 1 : 0);
            } else {
                applyCloudActivity(activityControl, update.activity, nowMs);
                Serial.printf("RELAY activity=%s seq=%lu override=%u\n",
                              userActivityName(update.activity),
                              static_cast<unsigned long>(update.activitySeq),
                              activityControl.serviceOverride ? 1 : 0);
            }
            refreshEffectiveActivity(nowMs, "relay");
        }
        if (!update.hasCommand) {
            continue;
        }

        const RelayDecision decision = consumeRelayCommand(
            relaySequence, update.command, currentActivity);
        if (decision.sequenceGap) {
            Serial.printf("RELAY command=gap seq=%lu missed=%lu\n",
                          static_cast<unsigned long>(update.command.seq),
                          static_cast<unsigned long>(decision.missedCount));
        }
        Serial.printf(
            "RELAY command=%s pattern=%s seq=%lu activity=%s route=%s\n",
            relayDispositionName(decision.disposition),
            cloudCommandName(update.command.pattern),
            static_cast<unsigned long>(update.command.seq),
            userActivityName(currentActivity), update.command.route);

        if (decision.disposition == RelayDisposition::ACCEPT) {
            submitCloudCommand(update.command.pattern,
                               cloudCommandName(update.command.pattern),
                               OutputTelemetrySource::RELAY);
        } else if (decision.disposition == RelayDisposition::NO_OUTPUT) {
            stopCloudPattern();
        }
    }
}

const char* currentlyPlayingName() {
    if (!outputLatch.enabled) {
        return "NONE";
    }
    if (sirenOutputActive()) {
        if (activeSirenOutput == SirenDecision::SIREN_WARNING) return "SIREN";
        return sirenDecisionName(activeSirenOutput);
    }
    if (cloudAvoidanceDirectionActive() &&
        patternOutput(cloudPlayer).active) {
        return cloudPlayer.pattern->name;
    }
    if (proximityOwnsOutput()) {
        return "PROXIMITY";
    }
    if (cloudPlayer.pattern == nullptr || !patternOutput(cloudPlayer).active) {
        return "NONE";
    }
    if (cloudPlayer.pattern == &NUMBER_PATTERN) {
        return "NUMBER";
    }
    return cloudPlayer.pattern->name;
}

const char* currentSirenPatternName() {
    if (!sirenOutputActive()) {
        return "NONE";
    }
    if (activeSirenOutput == SirenDecision::SIREN_WARNING) {
        return "SIREN";
    }
    return sirenDecisionName(activeSirenOutput);
}

const char* currentCloudPatternName() {
    if (cloudPlayer.pattern == nullptr || !patternOutput(cloudPlayer).active) {
        return "NONE";
    }
    return cloudPlayer.pattern == &NUMBER_PATTERN ? "NUMBER" :
                                                    cloudPlayer.pattern->name;
}
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
void loop() {
    serviceSerial();
    const uint32_t nowMs = millis();
    refreshEffectiveActivity(nowMs, "activity_lease");
    serviceRelay(nowMs);
    serviceAudio(nowMs);
    applyTofUpdate(tofService(nowMs), nowMs);
    serviceReady(nowMs);
    serviceOutput(nowMs);
    serviceOutputTelemetry(nowMs);
    serviceRelayTelemetry(nowMs);
    delay(1);
}

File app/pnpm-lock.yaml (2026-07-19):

lockfileVersion: '9.0'

settings:
  autoInstallPeers: true
  excludeLinksFromLockfile: false

importers:

  .:
    dependencies:
      '@anthropic-ai/sdk':
        specifier: ^0.112.3
        version: 0.112.3(zod@3.25.76)
      '@base-ui/react':
        specifier: ^1.6.0
        version: 1.6.0(@types/react@19.2.17)(react-dom@19.2.4(react@19.2.4))(react@19.2.4)
      '@upstash/redis':
        specifier: ^1.38.0
        version: 1.38.0
      class-variance-authority:
        specifier: ^0.7.1
        version: 0.7.1
      clsx:
        specifier: ^2.1.1
        version: 2.1.1
      lucide-react:
        specifier: ^1.25.0
        version: 1.25.0(react@19.2.4)
      next:
        specifier: 16.2.10
        version: 16.2.10(@babel/core@7.29.7)(react-dom@19.2.4(react@19.2.4))(react@19.2.4)
      react:
        specifier: 19.2.4
        version: 19.2.4
      react-dom:
        specifier: 19.2.4
        version: 19.2.4(react@19.2.4)
      shadcn:
        specifier: ^4.13.1
        version: 4.13.1(typescript@5.9.3)
      tailwind-merge:
        specifier: ^3.6.0
        version: 3.6.0
      tw-animate-css:
        specifier: ^1.4.0
        version: 1.4.0
    devDependencies:
      '@tailwindcss/postcss':
        specifier: ^4
        version: 4.3.3
      '@testing-library/dom':
        specifier: ^10.4.1
        version: 10.4.1
      '@testing-library/jest-dom':
        specifier: ^6.9.1
        version: 6.9.1
      '@testing-library/react':
        specifier: ^16.3.2
        version: 16.3.2(@testing-library/dom@10.4.1)(@types/react-dom@19.2.3(@types/react@19.2.17))(@types/react@19.2.17)(react-dom@19.2.4(react@19.2.4))(react@19.2.4)
      '@types/node':
        specifier: ^20
        version: 20.19.43
      '@types/react':
        specifier: ^19
        version: 19.2.17
      '@types/react-dom':
        specifier: ^19
        version: 19.2.3(@types/react@19.2.17)
      '@types/w3c-web-serial':
        specifier: ^1.0.8
        version: 1.0.8
      '@vitejs/plugin-react':
        specifier: ^6.0.3
        version: 6.0.3(vite@8.1.5(@types/node@20.19.43)(jiti@2.7.0))
      eslint:
        specifier: ^9
        version: 9.39.5(jiti@2.7.0)
      eslint-config-next:
        specifier: 16.2.10
        version: 16.2.10(@typescript-eslint/parser@8.64.0(eslint@9.39.5(jiti@2.7.0))(typescript@5.9.3))(eslint@9.39.5(jiti@2.7.0))(typescript@5.9.3)
      jsdom:
        specifier: ^29.1.1
        version: 29.1.1
      tailwindcss:
        specifier: ^4
        version: 4.3.3
      typescript:
        specifier: ^5
        version: 5.9.3
      vitest:
        specifier: ^4.1.10
        version: 4.1.10(@types/node@20.19.43)(jsdom@29.1.1)(vite@8.1.5(@types/node@20.19.43)(jiti@2.7.0))

packages:

  '@adobe/css-tools@4.5.0':
    resolution: {integrity: sha512-6OzddxPio9UiWTCemp4N8cYLV2ZN1ncRnV1cVGtve7dhPOtRkleRyx32GQCYSwDYgaHU3USMm84tNsvKzRCa1Q==}

  '@alloc/quick-lru@5.2.0':
    resolution: {integrity: sha512-UrcABB+4bUrFABwbluTIBErXwvbsU/V7TZWfmbgJfbkwiBuziS9gxdODUyuiecfdGQ85jglMW6juS3+z5TsKLw==}
    engines: {node: '>=10'}

  '@anthropic-ai/sdk@0.112.3':
    resolution: {integrity: sha512-wjcozJlitVIuBEw9cj/xBuRznwkhcLmXmNzlFoeHbh4AvrDG3HGZrdvEOTTmobcbhjGkfOpKbmDTCQ4s9LQvCg==}
    hasBin: true
    peerDependencies:
      zod: ^3.25.0 || ^4.0.0
    peerDependenciesMeta:
      zod:
        optional: true

  '@asamuzakjp/css-color@5.1.11':
    resolution: {integrity: sha512-KVw6qIiCTUQhByfTd78h2yD1/00waTmm9uy/R7Ck/ctUyAPj+AEDLkQIdJW0T8+qGgj3j5bpNKK7Q3G+LedJWg==}
    engines: {node: ^20.19.0 || ^22.12.0 || >=24.0.0}

  '@asamuzakjp/dom-selector@7.1.1':
    resolution: {integrity: sha512-67RZDnYRc8H/8MLDgQCDE//zoqVFwajkepHZgmXrbwybzXOEwOWGPYGmALYl9J2DOLfFPPs6kKCqmbzV895hTQ==}
    engines: {node: ^20.19.0 || ^22.12.0 || >=24.0.0}

  '@asamuzakjp/generational-cache@1.0.1':
    resolution: {integrity: sha512-wajfB8KqzMCN2KGNFdLkReeHncd0AslUSrvHVvvYWuU8ghncRJoA50kT3zP9MVL0+9g4/67H+cdvBskj9THPzg==}
    engines: {node: ^20.19.0 || ^22.12.0 || >=24.0.0}

  '@asamuzakjp/nwsapi@2.3.9':
    resolution: {integrity: sha512-n8GuYSrI9bF7FFZ/SjhwevlHc8xaVlb/7HmHelnc/PZXBD2ZR49NnN9sMMuDdEGPeeRQ5d0hqlSlEpgCX3Wl0Q==}

  '@babel/code-frame@7.29.7':
    resolution: {integrity: sha512-Aup7aUOfpbAUg2ROOJN6Iw5f9DMBlzu0mIkm/malLQFN/YQgO48wCj0Kxa3sEHJvPVFg7siR+qRInwXd2qhQKw==}
    engines: {node: '>=6.9.0'}

  '@babel/compat-data@7.29.7':
    resolution: {integrity: sha512-locTkQyKvwIEgBzVrn8693ebc97F2U8ZHjbXwDXJ5Fn2TCpNwTlKcaKLkdHop5c/icOFE7qt7Q9JC5hnKNa6Gg==}
    engines: {node: '>=6.9.0'}

  '@babel/core@7.29.7':
    resolution: {integrity: sha512-RgHBCvtjbOK2gXSNBNIkNoEc9qoVEtau3hj8gEqKQuL3HZAibKarWFEI3Lfm6EYKkLalOh8eSrj9b+ch9H/VBA==}
    engines: {node: '>=6.9.0'}

  '@babel/generator@7.29.7':
    resolution: {integrity: sha512-DkXD5OJQaAQIdZ1bt3UZdEnHAn9Imd3IVBdX03UFe+ony9Ojw5pzr9YVKGDY1jt+Gcn/FnGkNf8r+Vj5NOJWtQ==}
    engines: {node: '>=6.9.0'}
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

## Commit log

2026-07-17 Initial commit: speech-to-braille wearable plan, CAD, parts kit, and audit trail.
    Excludes secrets (.env) and local Python venv so the repo is safe to link to Vercel.
    [AX22-0003.step, AX22-0005.step, AX22-0011.step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]
2026-07-18 Add exocage CAD, firmware, web app, and full build audit trail.
    Ships printable STEP/STL geometry, the monolith enclosure Fusion script, Genesis Mini firmware, Next.js companion app, and audit docs covering the redesign through deploy smoke tests.
    [braille_wearable_cage.stl, braille_wearable_enclosure.step, braille_wearable_exocage.step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]
2026-07-18 Pivot to bus-stop situational awareness and archive superseded plans.
    Replace the speech-to-braille direction with a measured plan, audit trail, VL53L0CX part kit, and repo README so contributors know what is current and what is historical.
    [AX22-0015.step]
2026-07-18 docs(plan): swap ERMs for passive buzzers, mobile capture, L/R nav attempt
    Replace the two ERM motors (unsourceable in time) with two AX22-0018
    passive buzzers, driven low-frequency for a felt buzz. This flips the
    haptic drive model from duty-cycle amplitude to frequency/tone and
    reworks the vocabulary, route-number encoding, drive rules, power and
    CAD constraints accordingly.
    Move camera capture from the laptop Python client to a mobile getUserMedia
    web app in the Next.js app, reversing the prior locked decision and cutting
    vision/bus_client.py; the browser page inherits the detector-to-device
    translation role.
    Restore left/right navigation as an experimental P11-P13 block using
    per-side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
2026-07-18 chore(www): add .env.example template and track it in gitignore
2026-07-18 feat: add controlled buzzer discrimination runner
    [buzzer_experiment.cpp]
2026-07-18 feat(www): add device relay contract, redis state, and api routes
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2026-07-18 fix: switch failed haptics to audio proxies
    [buzzer_experiment.cpp]
2026-07-18 fix: extend ToF experiment range
    [tof_experiment.cpp]
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2026-07-18 Connect the web app to the Modal vision service (#7)
    * feat(vision): Modal YOLO-World detector with LVIS vocabulary
    Serves /ingest on a warm T4: one forward pass yields the drawn boxes, the
    arrival target and the hazard signal together. Claude reads the destination
    blind on a background thread behind a 3-vote gate, so an uncertain read
    returns nothing rather than a plausible-wrong route.
    The vocabulary is LVIS (1203 classes) plus two hand-tuned bus prompts, baked
    into the weights at image-build time so CLIP is never needed at runtime.
    Two consequences are designed for rather than discovered:
    - Class indices shift with the vocabulary, so the target and hazard maps
    resolve BY NAME. Keying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
    [AX22-0009.step, bus_stop_enclosure.step, bus_stop_enclosure.stl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]
2026-07-18 fix: complete board output contracts
    [haptic_pure.h, main.cpp, tof_experiment.cpp]
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2026-07-18 fix(firmware): heartbeat physical output state
    [haptic.cpp]
2026-07-18 fix(firmware): require high-confidence route 88
    [net.cpp]
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2026-07-18 fix(firmware): parse chunked relay responses
    [net.cpp]
2026-07-18 Feat/activity state pipeline (#14)
    * Add TACTA logo branding and pending research artifacts.
    Wire the wordmark into the web topbar and app icons, and check in bus-stop/modal audit notes plus the CAD step.
    * docs(vision): warn that Haiku rejects output_config.effort.
    Document the dual-call drop requirement so a model swap cannot silently force every arrival onto the UNREADABLE path.
    ---------
    [v2_20mm.step]
2026-07-18 fix(firmware): fail closed on stale activity
    [main.cpp, net.cpp, net.h]
2026-07-18 fix(firmware): revoke activity after relay outage
    [main.cpp]
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2026-07-18 feat(www): relay phone activity state to the board
    Adds the STILL/MOVING activity pipeline the firmware has been waiting on.
    /api/pull previously emitted no activity field at all, so the board's
    cloudActivity stayed UNKNOWN, effectiveActivity() returned its MOVING
    fallback, and acceptsRelayCommand() suppressed every bus command. This is
    what makes STILL reachable.
    - POST /api/activity as a dedicated setter, versioned independently of
    command seq. AGENTS.md: an activity heartbeat must not increment command
    seq or refresh an old command timestamp.
    - activitySeq is a Redis INCR counter, never a timestamp. Date.now() is
    ~1.78e12 and fails ArduinoJson is<uint32_t>(), which makes the board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
2026-07-18 docs(audit): record activity pipeline research and integration
    Files 14-18 of the bus-stop workstream.
    14 analyses Sebastian's PR #13 landing mid-flight and reframes this
    workstream around it: the firmware relay parser was dropped entirely rather
    than reimplemented, and LEFT/RIGHT/AHEAD were dropped as relay commands.
    15 is the implementation plan; 16 and 17 are the two web tracks; 18 is the
    review, deploy and live smoke record.
    Notable corrections to earlier assumptions, each verified against source:
    - The STILL default from issue #5 is stale. relay_pure.h fails safe to
    MOVING, so the relay must too.
    - HTTPClient already defaults _reuse = true, so setReuse(true) is a no-op.
    - The live r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
2026-07-18 chore: add slides, design skills, and vision research artifacts
    Slide deck and its STEP models, eleven design/3D skill packs, and the
    Modal vision research notes. Authored outside this workstream; committed
    together so the tree is clean before deploy.
    Claude-Session: https://claude.ai/code/session_01Hho2WbBfhWJxs2cCuPyUkx
    [ToF-AX22-0015.step, buzzer-1-AX22-0018.step, buzzer-2-AX22-0018.step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]
2026-07-18 feat(www): auto-detect walking and send bus bearing to the board
    Three fixes to what shipped earlier, all found by testing rather than review.
    Motion sensing was gated behind the camera. resumeSensor() was only
    reachable from "Start camera", so opening /capture and walking did nothing
    and the manual buttons looked like the whole feature. Adds startMotion()
    and a primary "Start motion detection" control; the Activity card moved
    outside the MODAL_URL guard, because walk detection needs neither a camera
    nor a Modal deployment.
    Auto is now the default once permission is granted. The manual buttons
    become "Force still / Force moving" under a Manual override subheading. An
    earlier instruction ma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
2026-07-18 feat(firmware): accept camera-derived bus bearing while moving
    The board parsed "LEFT" as INVALID and dropped it, so the direction the
    camera already computes could never reach the buzzers.
    - LEFT/RIGHT/AHEAD added to CloudCommand, parseCloudCommand and
    cloudCommandName. Ordinals are not load-bearing: the wire carries
    strings and nothing casts an int to the enum.
    - acceptsRelayCommand takes the three only while activity is MOVING,
    mirroring how BUS/NUMBER/WAIT/UNKNOWN are taken only while STILL. Bus
    information is the STILL payload; approach bearing is the MOVING one.
    This restores what navigation_pure.h did before the enum moved.
    - cloudPattern() in navigation_pure.h had to chang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
    [main.cpp]
2026-07-19 fix(www): detect slow walking cadences and add nav force-send override
    Real phones report accepted peaks at 40-50/min while walking (stride-rate
    detection), which the 850 ms stepMaxMs ceiling rejected wholesale, pinning
    the classifier on STILL and silently suppressing every LEFT/RIGHT/AHEAD
    nav command behind the MOVING guard. Widen the band to 1700 ms and the
    cadence window to 5000 ms (both x2), pin the 40 peaks/min regression in
    the test suite, and re-measure the peak-count and timing assertions the
    doubled window shifts.
    The camera->bearing->/api/event->board path was verified wired end to end;
    its only failure was the upstream activity gate. Add a Force send override
    so the bearing POST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
2026-07-19 chore: add slide deck build pipeline, frames and review notes
    Pre-existing uncommitted work carried onto main as-is: the deck's canvas
    frame sequence, build scripts (with heavy regenerable mesh/blend artifacts
    gitignored), and review notes.
    Claude-Session: https://claude.ai/code/session_01TimMqpQdQmkKqd8sWvnE4c
2026-07-19 feat: deliver bus bearings while standing still, scanning at the stop
    The user scans for the bus while STANDING STILL, so the first LEFT/RIGHT/
    AHEAD must reach the wearable before the first step - the old MOVING-only
    gate kept the board silent until ~4s into the walk. acceptsRelayCommand
    now accepts bearings in both known phases (UNKNOWN still refuses), and the
    phone's new pure chooseEvent() arbitrates the shared seq channel: bus info
    (BUS / NUMBER / UNKNOWN) outranks the bearing while STILL so arrival and
    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
2026-07-19 fix(slides): resolve 18 adversarial-review blockers across two passes
    Four reviewers (narrative/fact, visual/animation, anti-slop, pitch-practice)
    over two rounds. Fixes below are grouped by what would have gone wrong on stage.
    Claims the deck had not earned:
    - Slide 6 presented estimated latency as measured. The plan's tables are headed
    "Estimate", audit T4 Open Risk 7 says nothing in the architecture has been run,
    and T2 says verbatim "Do not put a latency number on a slide you have not
    measured." Now tilde + "not yet measured" credit + rehearsal instruction.
    - "Bus to route number - 3.8 s" was the wrong quantity. 3.8 s is to the first
    digit; P6 then takes 6.4 s. The slide contrad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
2026-07-19 docs(slides): finalise pitch-practice review
    Research audit against published pitch guidance. Key findings folded into the
    deck: O'Keefe 1999 on refutational vs non-refutational disclosure (slide 9),
    Rose and Ralston on live demos inside a pitch (recorded fallback), and Ralston
    on judges retaining 3-4 points at most.
    Also records what NOT to cite: the pratfall effect is not real evidence
    (Aronson 1966's headline result was not significant, t=1.45, p<.18), stealing
    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
2026-07-19 fix(slides): protect slide 9's refutation and fix the demo's visual channel
    Two findings from the pitch-practice research that reversed earlier decisions.
    The cut list was discarding the line that makes the honesty work.
    "We drove them down to seventy hertz. Still nothing." was marked CUTTABLE as
    "detail, not the claim". It is not detail - it is the only evidence-of-effort in
    slide 9, and therefore the only thing making that disclosure refutational rather
    than bare. O'Keefe 1999: refutational two-sided messages gain (r=+.077), while a
    weakness named and left hanging scores WORSE than silence (r=-.049). Combined
    with sign-off's "the tight run is the run" policy, the cut fired by default -
    in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
2026-07-19 fix(readiness): teach Sebastian's demo gate the bearing patterns and current toolchain
    Merged PR #16 (demo-flow hardening) and reconciled it with the audit-22/23
    direction work it predates. The readiness probe validated /api/pull against
    the six bus-information patterns only, so a relay holding LEFT/RIGHT/AHEAD
    - legal state in both activity phases since audit 23, and literally the
    live relay state today - reported NOT READY exactly when directions were
    working; the probe now mirrors contract.ts's nine CLOUD_PATTERNS with a
    regression test pinning a bearing pull. CI's pnpm 9.15.9 cannot frozen-
    install the pnpm-11 lockfile (settings block), so the workflow now pins
    pnpm 11.9.0 on Node 22. Ru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
2026-07-19 feat(motion): bias the classifier toward MOVING on any real movement
    Bench feedback after the audit-22 cadence fix: still had to walk hard to
    be detected - the limiter had moved to the amplitude gate (1.2 m/s^2
    smoothed prominence is ~3.4 m/s^2 raw). Per the stated demo requirement
    (STILL only when genuinely motionless), prominence drops to 0.45/0.25,
    the gate needs two peaks with one in-band interval instead of three with
    two, entry confirms in 500 ms (~1.2-1.8 s from first step), and the band
    ceiling stretches to a 2 s shuffle. The suite pins what survives: flat
    rest and +/-0.6 m/s^2 noise stay STILL over 60 s, 6 Hz shake and 0.4 Hz
    bumps still reject, gentle amp-1.5 walking now detects, c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
2026-07-19 fix: prepare firmware for morning demo
    [haptic_pure.h]
2026-07-19 feat(capture): extend bearing direction to persons when no bus in view
    Bus (target: true) remains preferred. If no bus is detected, the
    highest-confidence person detection feeds the same bearingFromBox →
    voteBearing → chooseEvent pipeline so LEFT/RIGHT/AHEAD commands are
    still delivered. NavView gains targetKind so the UI can label the
    section heading, readout, and diagnostics as "bus" or "person"
    contextually rather than hard-coding "bus".
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2026-07-19 fix(output): clear invalidated board activity
2026-07-19 fix(output): avoid false relay alerts
2026-07-19 feat(capture): use Claude Haiku vision to find clear path around person obstacles
    For the person/obstacle case (no bus in view), replace bearingFromBox
    with a POST to /api/person-direction that sends the raw frame to
    claude-haiku-4-5. Haiku analyzes the whole scene and returns left/right/ahead
    for the clearest path — the opposite intent from the bus case where we go
    *toward* the detected object.
    Rate-limited to one Haiku call per 1500 ms with a personAnalyzingRef guard
    against concurrent calls. The result is used directly as the bearing (no
    voteBearing needed). Bus path is entirely unchanged.
    Add /api/person-direction route with Anthropic SDK. Fail-safe: any Haiku
    error returns ahead so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
    [pnpm-lock.yaml]
2026-07-19 fix(person-direction): switch to claude-opus-4-5 for better spatial reasoning
2026-07-19 feat(vision): widen bus and person prompts with LVIS synonyms
    The single-word LVIS prompts "bus" and "person" were finicky on the demo
    scene — a clearly standing figure or a red double-decker sometimes scored
    below the 0.35 hazard/target floor because CLIP had one anchor to hit.
    Adding synonyms gives YOLO-World's text encoder multiple anchors for the
    same visual class; whichever fires strongest wins, then TARGET_LABELS and
    HAZARD_LABELS collapse the family back to one meaning so the phone still
    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
2026-07-19 fix(capture): show person direction instantly, refine with Claude
    The person / obstacle path had two bugs that stacked into "nothing on the
    screen" for a visible human on the bench:
    1. PERSON_MIN_CONFIDENCE at 0.35 matched Modal's hazard floor (CONF_MIN) but
    was much higher than the DRAW_CONF_MIN = 0.20 that the detector uses to
    admit a box in the first place. Real bench captures routinely scored a
    clearly standing person at 0.25–0.32 — drawn on the overlay, dropped by
    this gate, `personTarget` never resolved, UI said "Nothing in view".
    Lowered to 0.25: still above the pure jitter band, still catches genuine
    detections.
    2. When the person path fired, `personDirectionR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
2026-07-19 fix(detect): drop person confidence floor to 0.10 on both ends
    The client threshold was 0.25 and Modal's DRAW_CONF_MIN was 0.20 — real
    bench captures of a person routinely score in the 0.15–0.30 band with
    open-vocabulary YOLO-World (1212 classes now competing), so the pair
    silently dropped genuine detections and the phone said "Nothing in view"
    for a visible human.
    Both floors are now 0.10, matched deliberately: below Modal's floor a
    client-side value would do nothing anyway. The very low floor is safe
    here because the fast centroid-inverted path (added last commit) resolves
    the direction on the same 500 ms tick the person appears — a false
    positive at 0.10 costs at most one LEFT/RIGH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
2026-07-19 fix(web): report actual bearing activity
2026-07-19 fix(capture): restore instant person avoidance via centroid inversion
    Colleague's accessibility-cue hardening (cdfab14 / 365ee2b) made LEFT/RIGHT
    for a person depend solely on a high-confidence Claude result, and gated
    person target selection to MOVING. At typical YOLO scores (0.22–0.30) Claude
    usually returns low_confidence → guidance cleared → UI showed NONE while the
    person was clearly listed in view. Bus path was untouched and still worked.
    Restore the pre-hardening fast path without undoing the Claude refinement:
    - Select a person target whenever no bus is present (STILL and MOVING).
    - Emit LEFT/RIGHT on the same frame via invertBoxBearing(centroid).
    - Keep Claude as a MOVING-on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
2026-07-19 fix(firmware): reject broadband siren false positives
    [siren_pure.h]
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2026-07-19 fix(firmware): let directions interrupt proximity
    [main.cpp]
2026-07-20 chore: open-source cleanup and rename web app www to app
    Prepare the bus-stop situational-awareness prototype for open source.
    Remove closed speech-to-braille legacy: the old app/, the braille firmware
    sources and the braille test suite, the braille CAD sources, and the legacy
    renders. Stop tracking internal artifacts through .gitignore (audit/, slides/,
    plan/archive, plan/transcripts, docs/superpowers, root .claude/,
    skills-lock.json, WWW-STATE-OF-PLAY.md). They stay on local disk but leave the
    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
    [ToF-AX22-0015.step, braille_wearable_cage.stl, braille_wearable_drawing.dxf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]
2026-07-20 feat: reframe to the situational-awareness vision, ship deck as landing
    The bus is one hardcoded demo scene, not the product. Rename and reframe off
    the bus-only framing. cad/enclosure.py (was bus_stop_enclosure.py), the plan
    file, the CAD test, and all prose now describe the wider vision. A wearable
    that fuses cameras, microphones, and depth sensing into touch for DeafBlind
    people. Functional BUS relay commands and the route-88 demo lock stay.
    Ship the pitch deck as the tacta.space landing. next.config rewrites / to the
    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
    [AX22-0003.step, AX22-0005.step, AX22-0009.step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]
2026-07-21 fix(app): expose /output and /monitor from the capture header
    The deck now serves at /, so the capture page's "Monitor" button pointed at
    the deck instead of the relay monitor, and /output had no link from anywhere.
    Add Output and Monitor links to the capture header so both demo tools are
    discoverable.
    Claude-Session: https://claude.ai/code/session_0174A3f7r7Vp7kbbV2rxhp3q
2026-07-21 refactor(app): remove /monitor, braille-only topbar, deck-consistent CTA font
    Delete the relay monitor page (/monitor) entirely. Drop its link from the
    capture header (Output stays) and clean every doc reference.
    The topbar is now the braille wordmark alone. No Latin "TACTA", no bottom border.
    The end-of-deck CTA heading uses the deck display font (GT Cinetype), matching
    the .statement slides, instead of the serif.
    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
2026-07-21 style(app): braille favicon, drop the old logo, tab title just "Tacta"
    Replace the old logo favicon with a braille SVG (tacta in dots), wired for the
    app pages and the deck. Delete the unused logo.png, tacta-wide.png, and the
    Next icon.png convention file.
    Set every browser-tab title to "Tacta" (the deck no longer trails a long
    description).
    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
2026-07-21 docs: use the device photo as the README hero image
    Replace the exploded CAD render with a photo of the assembled prototype.
    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
